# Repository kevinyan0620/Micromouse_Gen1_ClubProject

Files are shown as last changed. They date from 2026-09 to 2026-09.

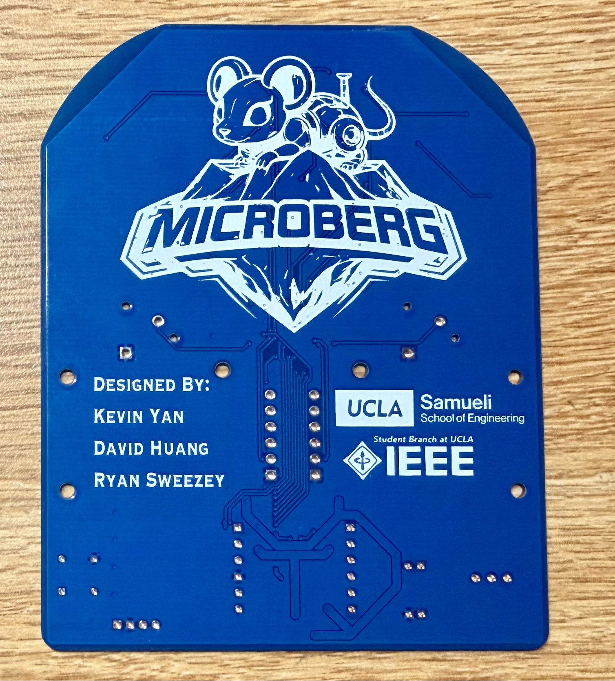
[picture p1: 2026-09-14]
Pictures/Design_Pictures.jpeg

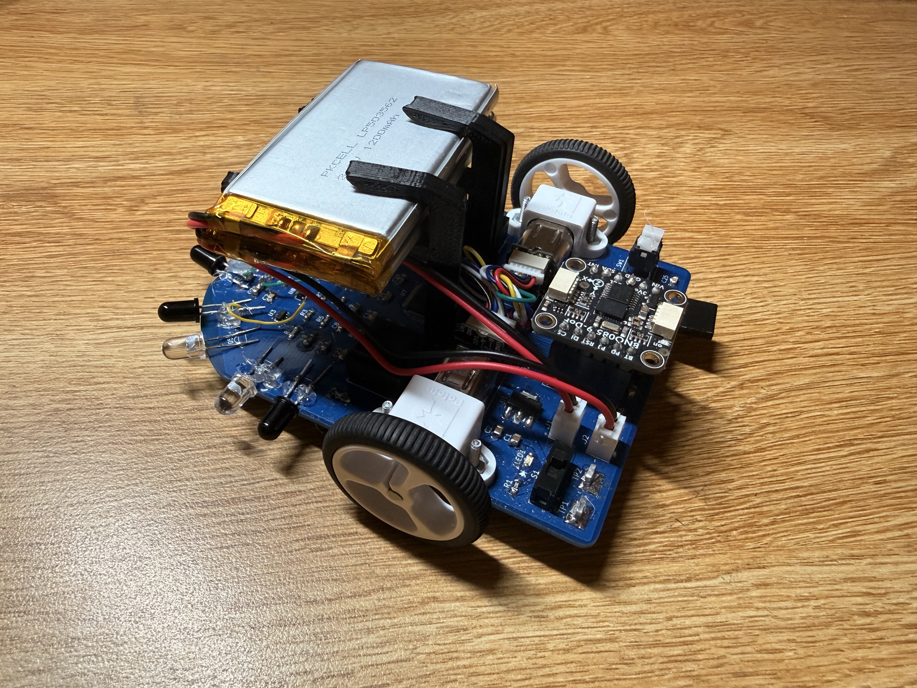
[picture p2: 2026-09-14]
Pictures/Micromouse_Pictures.jpeg

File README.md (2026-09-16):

# Autonomous Micromouse (Generation 1)

This repository details the hardware and firmware design of a Generation 1 autonomous Micromouse. Built from scratch, the project encompasses component selection, schematic capture, 2-layer PCB layout, and embedded C programming. 

Here is some pictures of our PCB design and our Micromouse!

| Our Group Logo | Final Micromouse |
| --- | --- |
|Design_Pictures |Micromouse_Pictures |

* **Competition Result:** Placed **5th Nationally** and **2nd Schoolwide** at the All American Micromouse Competition (AAMC).
* **See It In Action:** [Watch our competition run on AAMC Live (starts at 51:30)](https://youtu.be/dCLFL7v4gUA?t=3090)

We are actively iterating on this design to compete again in the upcoming AAMC!

## Repository Structure

* `/Micromouse_STM32ApplicationCode`: Contains the embedded C firmware and project files configured for the STM32 environment.

* `/The Mouse`: The master KiCad project directory. Includes the full system schematics (wiring) and the 2-layer PCB layout files.

* `/Micromouse_Parts`: Custom KiCad footprint and symbol libraries created for this project. These can be directly imported into KiCad for viewing or reuse.

* `/Pictures`: Photographic documentation of the hardware assembly, revisions, and competition runs.

* `Final Pinout.png`: A comprehensive STM32 pin mapping reference diagram required to understand the hardware-firmware interface.

* `Micromouse_BillOfMaterials_AssemblyVersion.xlsx`: A detailed assembly BOM mapped by reference designator (e.g., R10) and subsystem, used for manufacturing guidance and population.

* `Micromouse_BillOfMaterials_SubmitVersion.xlsx`: A consolidated purchasing BOM with grouped components and quantities, optimized for vendor procurement (e.g., Digi-Key).

* `Test_Run_With_Small_Maze.MOV`: Video demonstration of the maze-solving algorithm in a scaled-down test environment prior to the competition.

## Hardware Architecture

The electrical hardware was designed to balance form factor with sensor coverage and ease of routing. Components were carefully sourced via Digi-Key, maintaining a strict Bill of Materials (BOM) throughout the project lifecycle.

*   **Microcontroller:** STM32 MCU (STM32F205RET7) serving as the core processor, with pinouts optimized during the layout phase to minimize trace crossings and accommodate physical wiring constraints.
*   **PCB Design:** A fully hand-soldered, custom 2-layer board. Components were sourced via Digi-Key with a comprehensive Bill of Materials (BOM) managed throughout the project lifecycle.
*   **Sensor Array:** Custom 45-degree angled IR sensor placement for superior wall-detection accuracy compared to standard orthogonal layouts.
*   **Inertial Measurement:** Adafruit BNO085 9-DOF IMU (Gyroscope/Accelerometer) integrated to ensure highly accurate, drift-compensated turns.
*   **User Interface:** 4 onboard user LEDs and 2 tactile buttons for rapid field-diagnostics and mode switching.

## Firmware and Control Systems

The software stack is written entirely in bare-metal C, focusing on real-time control and algorithmic efficiency.

*   **Navigation:** Implemented a flood-fill algorithm for autonomous maze solving and optimal path calculation.
*   **Motor Control:** Closed-loop PID control utilizing encoder feedback to maintain precise velocities.
*   **Traction Management:** Engineered acceleration and deceleration profiles to prevent wheel slip, ensuring accurate encoder tick counts.
*   **Physical Realignment:** The mouse was designed to purposefully "tap" the wall during the run once every 10 actions (forward or turning), when appropriate. This is done by moving forward to tap the front wall, then slightly back up to the center of the maze. This helps realign the micromouse in the maze and avoid tiny errors from accumulating and ruining the run.
*   **Operational Modes:** Designed a dual-mode system allowing a seamless transition from "Search Mode" (active IR and flood-fill) to "Speed Run Mode" (sensorless execution of the stored optimal path).

## Assembly, Debugging, and Rework

Building the physical hardware required extensive hands-on debugging, microscope soldering, and creative problem-solving.

| Challenge | Root Cause | Engineering Solution |
| :--- | :--- | :--- |
| **Broken PCB Pad** | Mechanical stress / heat | Reworked using a microscope and microscopic gauge wire to bridge the broken connection. |
| **MCU Assembly** | Fine-pitch footprint | Successfully hand-soldered the tiny MCU using heavy flux, a microscope, and drag-soldering techniques within two attempts. |
| **IR Sensor Verification** | Invisible IR spectrum | Utilized a smartphone camera to detect the IR emitter's dim purple glow, and a phone flashlight (which emits IR) to stimulate and test the IR receivers. |

## Lessons Learned & Generation 2 Roadmap

This first iteration provided invaluable lessons in Design for Manufacturability (DFM) and edge-case software handling. The following improvements are slated for the Generation 2 Micromouse:

*   **Component Selection:** Transitioning from Surface Mount (SMD) IR sensors to Through-Hole (THT) alternatives. SMD optoelectronics proved highly susceptible to thermal damage during hand-soldering.
*   **Connector Standardization:** Replacing the non-standard ST-Link header with a standard 0.1-inch pitch 1x4 connector to streamline firmware flashing.
*   **Firmware Edge Cases:** Patching a known bug that occasionally causes indefinite looping turns under extreme, undocumented maze conditions.
*   **Path Optimization:** Upgrading the Speed Run mode algorithm to calculate and execute diagonal movements, significantly reducing cornering time.

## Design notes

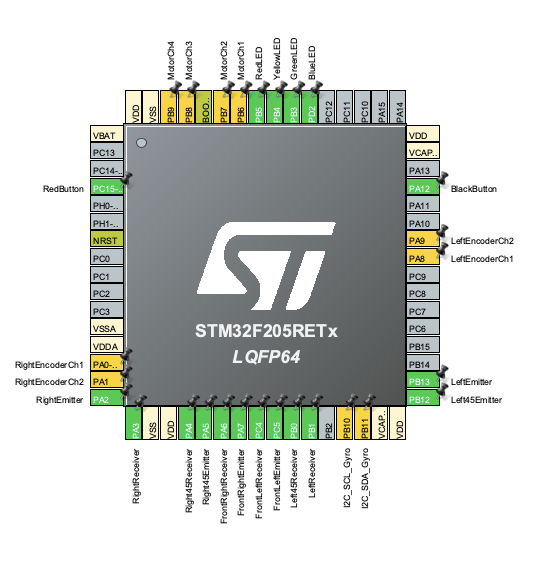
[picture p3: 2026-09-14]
Final Pinout.png

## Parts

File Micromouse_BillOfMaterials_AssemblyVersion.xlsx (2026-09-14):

Category | Item | Product Number | Designators | Detail | Quantity | Unit Price | Purchase Link | Datasheet | Notes |  | Total Price | 172.47
Power Delivery | Voltage Regulator | AZ1117IH-3.3TRG1 | U1 | Linear Voltage Regulator IC Positive Fixed 1 Output 1A SOT-223-3 | 1 | 0.24 | https://www.digikey.com/en/products/detail/diodes-incorporated/AZ1117IH-3-3TRG1/5699682 | https://www.diodes.com/assets/Datasheets/AZ1117I.pdf
Power Delivery | Capacitor | GRM21BR61C106KE15L | C1 | 10 µF ±10% 16V Ceramic Capacitor X5R 0805 (2012 Metric) | 1 | 0.13 | https://www.digikey.com/en/products/detail/murata-electronics/GRM21BR61C106KE15L/965900 | https://search.murata.co.jp/Ceramy/image/img/A01X/G101/ENG/GRM21BR61C106KE15-01.pdf | Input Decoupling |  | Submit Version (https://docs.google.com/spreadsheets/d/1v3HhBURM-rz71dSanRjxjPIMUvfi7GNW-tEQRfmBjM0/edit?usp=sharing)
Power Delivery | Capacitor | CL21A226KOQNNNE | C2 | 22 µF ±10% 16V Ceramic Capacitor X5R 0805 (2012 Metric) | 1 | 0.33 | https://www.digikey.com/en/products/detail/samsung-electro-mechanics/CL21A226KOQNNNE/5961010 | https://mm.digikey.com/Volume0/opasdata/d220001/medias/docus/6462/CL21A226KOQNNNE-datasheet.pdf | Output Decoupling |  | https://www.digikey.com/en/products/detail/same-sky-formerly-cui-devices/SSK02-FPH-254-A4/28772197
Power Delivery | JST Connector | B2B-PH-K-S | J1, J2 | Connector Header Through Hole 2 position 0.079" (2.00mm) | 2 | 0.1 | https://www.digikey.com/en/products/detail/jst-sales-america-inc/B2B-PH-K-S-LF-SN/455-1704-ND/926611 | https://www.jst-mfg.com/product/pdf/eng/ePH.pdf | Battery JST Connector |  | https://www.digikey.com/en/products/detail/ams-osram-usa-inc/SFH-313-FA-3-4/1630112
Power Delivery | Switch | EG1218 | S1 | Slide Switch SPDT Through Hole | 1 | 0.84 | https://www.digikey.com/en/products/detail/e-switch/EG1218/101726 | https://configured-product-images.s3.amazonaws.com/Datasheets/EG.pdf | Switch On/Off |  | https://www.digikey.com/en/products/detail/inolux/INL-5AMIR15/10384755
Power Delivery | Green LED | LTST-C170GKT | LED1 | Green 569nm LED Indication - Discrete 2.1V 0805 (2012 Metric) | 1 | 0.1 | https://www.digikey.com/en/products/detail/liteon/LTST-C170GKT/269226 | https://mm.digikey.com/Volume0/opasdata/d220001/medias/docus/895/LTST-C170GKT.pdf | Power On/Off Indicator
Power Delivery | Resistor | ERA-6AEB221V | R1 | 220 Ohms ±0.1% 0.125W, 1/8W Chip Resistor 0805 (2012 Metric) Automotive AEC-Q200 Thin Film | 1 | 0.1 | https://www.digikey.com/en/products/detail/panasonic-electronic-components/ERA-6AEB221V/1465732 | https://industrial.panasonic.com/cdbs/www-data/pdf/RDM0000/AOA0000C307.pdf | Power LED Resistor
Power Delivery | Test Point Pins | 5095 | TP1, TP2 | PC Test Point, Compact Phosphor Bronze Tin Plating Surface Mount Mounting Type | 2 | 0.4 | https://www.digikey.com/en/products/detail/keystone-electronics/5095/12751699 | http://www.keystoneelectronics.biz/ENG._DEPT/WEB_ORACLE/PDF/PDF%20CAT%20NO%20DRAWINGS/5000-5999/5095.PDF | Test Point for VBat and GND
Motor Control | H Bridge IC | L293DD | U2 | Bipolar Motor Driver Parallel 20-SO | 1 | 8.56 | https://www.digikey.com/en/products/detail/stmicroelectronics/L293DD/585913 | https://www.st.com/content/ccc/resource/technical/document/datasheet/04/ac/22/f9/20/5d/43/a1/CD00000059.pdf/files/CD00000059.pdf/jcr:content/translations/en.C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 | Motor Control H Bridge
Motor Control | Capacitor | GRM21BR61C106KE15L | C3 | 10 µF ±10% 16V Ceramic Capacitor X5R 0805 (2012 Metric) | 1 | 0.13 | https://www.digikey.com/en/products/detail/murata-electronics/GRM21BR61C106KE15L/965900 | https://search.murata.co.jp/Ceramy/image/img/A01X/G101/ENG/GRM21BR61C106KE15-01.pdf | Vs Decoupling 1 | Same as 3
Motor Control | Capacitor | VJ0805Y104JXAAT | C5 | 0.1 µF ±5% 50V Ceramic Capacitor X7R 0805 (2012 Metric) | 1 | 0.39 | https://www.digikey.com/en/products/detail/vishay-vitramon/VJ0805Y104JXAAT/2776727 | https://www.vishay.com/docs/45199/vjcommercialseries.pdf | Vss Decoupling 1
Motor Control | Capacitor | GRT21BR61H475KE13L | C4, C6 | 4.7 µF ±10% 50V Ceramic Capacitor X5R 0805 (2012 Metric) | 2 | 0.17 | https://www.digikey.com/en/products/detail/murata-electronics/GRT21BR61H475KE13L/5416816 | https://search.murata.co.jp/Ceramy/image/img/A01X/G101/ENG/GRT21BR61H475KE13-01.pdf | Vs Decoupling 2; Vss Decoupling 2
IR Emitter | Capacitor | VJ0805Y104JXAAT | C8, C10, C12, C14, C29, C31 | 0.1 µF ±5% 50V Ceramic Capacitor X7R 0805 (2012 Metric) | 6 | 0.39 | https://www.digikey.com/en/products/detail/vishay-vitramon/VJ0805Y104JXAAT/2776727 | https://www.vishay.com/docs/45199/vjcommercialseries.pdf | IR Emitter Bypass 1 | Same as 13
IR Emitter | Capacitor | GRT21BR61H475KE13L | C7, C9, C11, C13, C28, C30 | 4.7 µF ±10% 50V Ceramic Capacitor X5R 0805 (2012 Metric) | 6 | 0.17 | https://www.digikey.com/en/products/detail/murata-electronics/GRT21BR61H475KE13L/5416816 | https://search.murata.co.jp/Ceramy/image/img/A01X/G101/ENG/GRT21BR61H475KE13-01.pdf | IR Emitter Bypass 2 | Same as 14
IR Emitter | IR Emitter | INL-5AMIR15 | D1, D2, D3, D4, D5, D6 | Infrared (IR) Emitter 880nm 1.3V 100mA 7.8mW/sr @ 20mA 15° Radial | 6 | 0.92 | https://www.digikey.com/en/products/detail/inolux/INL-5AMIR15/10384755 | https://www.inolux-corp.com/datasheet/IR/Emitter/5mm%20Lamp/INL-5AMIR15_V1.0.pdf
IR Emitter | MOSFET | MMBF170LT1G | U3, U4, U5, U6, U8, U9 | N-Channel 60 V 500mA (Ta) 225mW (Ta) Surface Mount SOT-23-3 (TO-236) | 6 | 0.26 | https://www.digikey.com/en/products/detail/onsemi/MMBF170LT1G/919578 | https://www.onsemi.com/pdf/datasheet/mmbf170lt1-d.pdf
IR Emitter | Resistor | ERA-6AEB101V | R2, R6, R10, R14, R26, R30 | 100 Ohms ±0.1% 0.125W, 1/8W Chip Resistor 0805 (2012 Metric) Automotive AEC-Q200 Thin Film | 6 | 0.1 | https://www.digikey.com/en/products/detail/panasonic-electronic-components/ERA-6AEB101V/1465724 | https://industrial.panasonic.com/cdbs/www-data/pdf/RDM0000/AOA0000C307.pdf | MCU Pin Current Limiter Resistor
IR Emitter | Resistor | ERA-6AEB510V | R4, R8, R12, R16, R28, R32 | 51 Ohms ±0.1% 0.125W, 1/8W Chip Resistor 0805 (2012 Metric) Automotive AEC-Q200 Thin Film | 6 | 0.1 | https://www.digikey.com/en/products/detail/panasonic-electronic-components/ERA-6AEB510V/1465717 | https://industrial.panasonic.com/cdbs/www-data/pdf/RDM0000/AOA0000C307.pdf | IR Emitter Resistor
IR Emitter | Resistor | ERA-6AEB473V | R3, R7, R11, R15, R27, R31 | 47 kOhms ±0.1% 0.125W, 1/8W Chip Resistor 0805 (2012 Metric) Automotive AEC-Q200 Thin Film | 6 | 0.1 | https://www.digikey.com/en/products/detail/panasonic-electronic-components/ERA-6AEB473V/1465789 | https://industrial.panasonic.com/cdbs/www-data/pdf/RDM0000/AOA0000C307.pdf | Pull Down Resistor
IR Receiver | IR Receiver | SFH 313 FA-3/4 | Q1, Q2, Q3, Q4, Q5, Q6 | Phototransistors 870nm Top View Radial | 6 | 0.83 | https://www.digikey.com/en/products/detail/ams-osram-usa-inc/SFH-313-FA-3-4/1630112 | https://look.ams-osram.com/m/5f84917e436bcd12/original/SFH-313-FA.pdf
IR Receiver | Resistor | ERA-6AEB182V | R5, R9, R13, R17, R29, R33 | 1.8 kOhms ±0.1% 0.125W, 1/8W Chip Resistor 0805 (2012 Metric) Automotive AEC-Q200 Thin Film | 6 | 0.1 | https://www.digikey.com/en/products/detail/panasonic-electronic-components/ERA-6AEB182V/1465755 | https://industrial.panasonic.com/cdbs/www-data/pdf/RDM0000/AOA0000C307.pdf | IR Reciever Limiting Resistor
Microcontroller | STM 32 | STM32F205RET7 | U7 | High-performance Arm Cortex-M3 MCU with 512 Kbytes of Flash memory, 120 MHz CPU, ART Accelerator | 1 | 11.52 | https://estore.st.com/en/stm32f205ret7-cpn.html | https://www.st.com/resource/en/datasheet/stm32f205rb.pdf
Microcontroller | Capacitor | VJ0805Y104JXAAT | C17, C18, C19, C21, C22, C24, C25 | 0.1 µF ±5% 50V Ceramic Capacitor X7R 0805 (2012 Metric) | 6 | 0.39 | https://www.digikey.com/en/products/detail/vishay-vitramon/VJ0805Y104JXAAT/2776727 | https://www.vishay.com/docs/45199/vjcommercialseries.pdf | Microcontroller Decoupling Capacitor | Same as 13
Microcontroller | Capacitor | GRM21BC72A105KE01L | C23 | 1 µF ±10% 100V Ceramic Capacitor X7S 0805 (2012 Metric) | 1 | 0.36 | https://www.digikey.com/en/products/detail/murata-electronics/GRM21BC72A105KE01L/6606093 | https://search.murata.co.jp/Ceramy/image/img/A01X/G101/ENG/GRM21BC72A105KE01-01.pdf | Microcontroller Decoupling Capacitor
Microcontroller | Capacitor | GRM21BD72A225KE01L | C15, C16 | 2.2 µF ±10% 100V Ceramic Capacitor X7T 0805 (2012 Metric) | 2 | 0.4 | https://www.digikey.com/en/products/detail/murata-electronics/GRM21BD72A225KE01L/16033492 | https://search.murata.co.jp/Ceramy/image/img/A01X/G101/ENG/GRM21BD72A225KE01-01A.pdf | Microcontroller Decoupling Capacitor
Microcontroller | Capacitor | GRM21BR61C106KE15L | C20 | 10 µF ±10% 16V Ceramic Capacitor X5R 0805 (2012 Metric) | 1 | 0.13 | https://www.digikey.com/en/products/detail/murata-electronics/GRM21BR61C106KE15L/965900 | https://search.murata.co.jp/Ceramy/image/img/A01X/G101/ENG/GRM21BR61C106KE15-01.pdf | Microcontroller Decoupling Capacitor | Same as 3
Microcontroller | Resistor | ERA-6AEB103V | R18, R19 | 10 kOhms ±0.1% 0.125W, 1/8W Chip Resistor 0805 (2012 Metric) Automotive AEC-Q200 Thin Film | 2 | 0.1 | https://www.digikey.com/en/products/detail/panasonic-electronic-components/ERA-6AEB103V/1465773 | https://industrial.panasonic.com/cdbs/www-data/pdf/RDM0000/AOA0000C307.pdf | Microcontroller Resistor
Microcontroller | Pushbutton | TR1-01 | SW1 | Pushbutton Switch SPST-NO Standard Through Hole | 1 | 0.86 | https://www.digikey.com/en/products/detail/nidec-components-corporation/TR1-01/5125294 | https://www.nidec-components.com/e/catalog/switch/tm&tr.pdf | Microcontroller Reset Button
Microcontroller | Female Socket | SSK02-FPH-254-A4 | J5 | 4 Position Header Connector 0.100" (2.54mm) Through Hole Gold | 1 | 0.32 | https://www.digikey.com/en/products/detail/same-sky-formerly-cui-devices/SSK02-FPH-254-A4/28772197 | https://www.sameskydevices.com/product/resource/ssk02-fph-254.pdf | Socket for ST Link
User LED | Resistor | ERA-6AEB221V | R20, R21, R22, R23 | 220 Ohms ±0.1% 0.125W, 1/8W Chip Resistor 0805 (2012 Metric) Automotive AEC-Q200 Thin Film | 4 | 0.1 | https://www.digikey.com/en/products/detail/panasonic-electronic-components/ERA-6AEB221V/1465732 | https://industrial.panasonic.com/cdbs/www-data/pdf/RDM0000/AOA0000C307.pdf | User LED Resistor
User LED | Red LED | LTST-C171KRKT | LED2 | Red 631nm LED Indication - Discrete 2V 0805 (2012 Metric) | 1 | 0.13 | https://www.digikey.com/en/products/detail/liteon/LTST-C171KRKT/386801 | https://optoelectronics.liteon.com/upload/download/DS22-2000-109/LTST-C171KRKT.pdf | User Red LED
User LED | Yellow LED | LTST-C170KSKT | LED3 | Yellow 591nm LED Indication - Discrete 2.1V 0805 (2012 Metric) | 1 | 0.14 | https://www.digikey.com/en/products/detail/liteon/LTST-C170KSKT/386781 | https://optoelectronics.liteon.com/upload/download/DS-22-99-0188/LTST-C170KSKT.pdf | User Yellow LED
User LED | Green LED | LTST-C170GKT | LED4 | Green 569nm LED Indication - Discrete 2.1V 0805 (2012 Metric) | 1 | 0.1 | https://www.digikey.com/en/products/detail/liteon/LTST-C170GKT/269226 | https://mm.digikey.com/Volume0/opasdata/d220001/medias/docus/895/LTST-C170GKT.pdf | User Green LED
User LED | Blue LED | LTST-C170TBKT | LED5 | Blue 470nm LED Indication - Discrete 3.3V 0805 (2012 Metric) | 1 | 0.22 | https://www.digikey.com/en/products/detail/liteon/LTST-C170TBKT/388527 | https://optoelectronics.liteon.com/upload/download/DS-22-99-0226/LTST-C170TBKT.pdf | User Blue LED
User Button | Capacitor | VJ0805Y104JXAAT | C26, C27 | 0.1 µF ±5% 50V Ceramic Capacitor X7R 0805 (2012 Metric) | 2 | 0.39 | https://www.digikey.com/en/products/detail/vishay-vitramon/VJ0805Y104JXAAT/2776727 | https://www.vishay.com/docs/45199/vjcommercialseries.pdf | User Button Debouncing | Same as 13
User Button | Resistor | ERA-6AEB472V | R24, R25 | 4.7 kOhms ±0.1% 0.125W, 1/8W Chip Resistor 0805 (2012 Metric) Automotive AEC-Q200 Thin Film | 2 | 0.1 | https://www.digikey.com/en/products/detail/panasonic-electronic-components/ERA-6AEB472V/1465765 | https://industrial.panasonic.com/cdbs/www-data/pdf/RDM0000/AOA0000C307.pdf | User Button Pull-up Resistor
User Button | Push Button | KS11R22CQD | SW2 | Pushbutton Switch SPST-NO Keyswitch Through Hole | 1 | 2.84 | https://www.digikey.com/en/products/detail/c-k/KS11R22CQD/332670 | https://www.ckswitches.com/media/1342/ks.pdf | Black User Button
User Button | Push Button | KS11R23CQD | SW3 | Pushbutton Switch SPST-NO Keyswitch Through Hole | 1 | 2.84 | https://www.digikey.com/en/products/detail/c-k/KS11R23CQD/332672 | https://www.ckswitches.com/media/1342/ks.pdf | Red User Button
Gyroscope | Gyroscope | 4754 | On top of J6, J7 | Adafruit 9-DOF Orientation IMU Fusion Breakout - BNO085 (BNO080) - STEMMA QT / Qwiic | 1 | 24.95 | https://www.adafruit.com/product/4754#technical-details | https://cdn-learn.adafruit.com/downloads/pdf/adafruit-9-dof-orientation-imu-fusion-breakout-bno085.pdf
Gyroscope | Socket | D01-9970642 | J6, J7 | 6 (1 x 6) Pos SIP Socket Gold Through Hole | 2 | 0.63 | https://www.digikey.com/en/products/detail/harwin-inc/D01-9970642/3727951 | https://content.harwin.com/m/e0b6c35948424a73/original/DRG-00097-Technical-Drawing-Datasheet-D01-997-pdf.pdf | Socket for Gyroscope
Hardware | Motor | 2378 | NA | 30:1 Micro Metal Gearmotor MP 6V with Extended Motor Shaft | 2 | 24.95 | https://www.pololu.com/product/2378
Hardware | Encoder Pair | 4760 | NA | Magnetic Encoder Pair Kit with Top-Entry Connector for Micro Metal Gearmotors, 12 CPR, 2.7-18V | 1 | 8.95 | https://www.pololu.com/product/4760
Hardware | Motor Mount | 1086 | NA | Pololu Micro Metal Gearmotor Bracket Pair - White | 1 | 2.95 | https://www.pololu.com/product/1086
Hardware | Wheels | 1088 | NA | Pololu Wheel 32×7mm Pair - White | 1 | 4.45 | https://www.pololu.com/product/1088
Hardware | LiPo Battery | 258 | NA | Lithium Ion Polymer Battery - 3.7v 1200mAh | 2 | 9.95 | https://www.adafruit.com/product/258
Hardware | LiPo Battery Charger | 1304 | NA | Adafruit Micro Lipo - USB LiIon/LiPoly charger - v2 | 1 | 5.95 | https://www.adafruit.com/product/1304

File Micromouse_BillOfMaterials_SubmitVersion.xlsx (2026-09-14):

Item | Product Number | Detail | Quantity | Unit Price | Purchase Link | Datasheet | Notes | Total Price | 211.09
Voltage Regulator | AZ1117IH-3.3TRG1 | Linear Voltage Regulator IC Positive Fixed 1 Output 1A SOT-223-3 | 1 | 0.24 | https://www.digikey.com/en/products/detail/diodes-incorporated/AZ1117IH-3-3TRG1/5699682 | https://www.diodes.com/assets/Datasheets/AZ1117I.pdf
Capacitor | GRM21BR61C106KE15L | 10 µF ±10% 16V Ceramic Capacitor X5R 0805 (2012 Metric) | 6 | 0.13 | https://www.digikey.com/en/products/detail/kyocera-avx/0805YD106KAT2A/1913255 | https://search.murata.co.jp/Ceramy/image/img/A01X/G101/ENG/GRM21BR61C106KE15-01.pdf | Input Decoupling | Old Order: https://www.digikey.com/en/products/detail/murata-electronics/GRM21BR61C106KE15L/965900
Capacitor | CL21A226KOQNNNE | 22 µF ±10% 16V Ceramic Capacitor X5R 0805 (2012 Metric) | 3 | 0.33 | https://www.digikey.com/en/products/detail/samsung-electro-mechanics/CL21A226KOQNNNG/8021509 | https://mm.digikey.com/Volume0/opasdata/d220001/medias/docus/6462/CL21A226KOQNNNE-datasheet.pdf | Output Decoupling | Old Order: https://www.digikey.com/en/products/detail/samsung-electro-mechanics/CL21A226KOQNNNE/5961010
JST Connector | B2B-PH-K-S | Connector Header Through Hole 2 position 0.079" (2.00mm) | 2 | 0.1 | https://www.digikey.com/en/products/detail/jst-sales-america-inc/B2B-PH-K-S-LF-SN/455-1704-ND/926611 | https://www.jst-mfg.com/product/pdf/eng/ePH.pdf | Battery JST Connector
Switch | EG1218 | Slide Switch SPDT Through Hole | 1 | 0.84 | https://www.digikey.com/en/products/detail/e-switch/EG1218/101726 | https://configured-product-images.s3.amazonaws.com/Datasheets/EG.pdf | Switch On/Off
Green LED | LTST-C170GKT | Green 569nm LED Indication - Discrete 2.1V 0805 (2012 Metric) | 3 | 0.1 | https://www.digikey.com/en/products/detail/liteon/LTST-C170GKT/269226 | https://mm.digikey.com/Volume0/opasdata/d220001/medias/docus/895/LTST-C170GKT.pdf | Power On/Off Indicator
Resistor | ERA-6AEB221V | 220 Ohms ±0.1% 0.125W, 1/8W Chip Resistor 0805 (2012 Metric) Automotive AEC-Q200 Thin Film | 3 | 0.1 | https://www.digikey.com/en/products/detail/panasonic-electronic-components/ERA-6AEB221V/1465732 | https://industrial.panasonic.com/cdbs/www-data/pdf/RDM0000/AOA0000C307.pdf | Power LED Resistor
Test Point Pins | 5095 | PC Test Point, Compact Phosphor Bronze Tin Plating Surface Mount Mounting Type | 4 | 0.4 | https://www.digikey.com/en/products/detail/keystone-electronics/5095/12751699 | http://www.keystoneelectronics.biz/ENG._DEPT/WEB_ORACLE/PDF/PDF%20CAT%20NO%20DRAWINGS/5000-5999/5095.PDF | Test Point for VBat and GND
H Bridge IC | L293DD | Bipolar Motor Driver Parallel 20-SO | 2 | 8.56 | https://www.digikey.com/en/products/detail/stmicroelectronics/L293DD/585913 | https://www.st.com/content/ccc/resource/technical/document/datasheet/04/ac/22/f9/20/5d/43/a1/CD00000059.pdf/files/CD00000059.pdf/jcr:content/translations/en.C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 | Motor Control H Bridge
Capacitor | VJ0805Y104JXAAT | 0.1 µF ±5% 50V Ceramic Capacitor X7R 0805 (2012 Metric) | 18 | 0.39 | https://www.digikey.com/en/products/detail/kemet/C0805C104J5RACTU/411446 | https://www.vishay.com/docs/45199/vjcommercialseries.pdf | Vss Decoupling 1 | Old Order: https://www.digikey.com/en/products/detail/vishay-vitramon/VJ0805Y104JXAAT/2776727
Capacitor | GRT21BR61H475KE13L | 4.7 µF ±10% 50V Ceramic Capacitor X5R 0805 (2012 Metric) | 9 | 0.17 | https://www.digikey.com/en/products/detail/murata-electronics/GRT21BR61H475KE13L/5416816 | https://search.murata.co.jp/Ceramy/image/img/A01X/G101/ENG/GRT21BR61H475KE13-01.pdf | Vs Decoupling 2; Vss Decoupling 2
IR Emitter | INL-5AMIR15 | Infrared (IR) Emitter 880nm 1.3V 100mA 7.8mW/sr @ 20mA 15° Radial | 7 | 0.92 | https://www.digikey.com/en/products/detail/inolux/INL-5AMIR15/10384755 | https://www.inolux-corp.com/datasheet/IR/Emitter/5mm%20Lamp/INL-5AMIR15_V1.0.pdf
MOSFET | MMBF170LT1G | N-Channel 60 V 500mA (Ta) 225mW (Ta) Surface Mount SOT-23-3 (TO-236) | 8 | 0.26 | https://www.digikey.com/en/products/detail/onsemi/FDN5630/965610 | https://www.onsemi.com/pdf/datasheet/mmbf170lt1-d.pdf |  | Old Order: https://www.digikey.com/en/products/detail/onsemi/MMBF170LT1G/919578
Resistor | ERA-6AEB101V | 100 Ohms ±0.1% 0.125W, 1/8W Chip Resistor 0805 (2012 Metric) Automotive AEC-Q200 Thin Film | 8 | 0.1 | https://www.digikey.com/en/products/detail/susumu/RG2012P-101-B-T5/1241036 | https://industrial.panasonic.com/cdbs/www-data/pdf/RDM0000/AOA0000C307.pdf | MCU Pin Current Limiter Resistor | Old Order: https://www.digikey.com/en/products/detail/panasonic-electronic-components/ERA-6AEB101V/1465724
Resistor | ERA-6AEB510V | 51 Ohms ±0.1% 0.125W, 1/8W Chip Resistor 0805 (2012 Metric) Automotive AEC-Q200 Thin Film | 8 | 0.1 | https://www.digikey.com/en/products/detail/panasonic-electronic-components/ERA-6AEB510V/1465717 | https://industrial.panasonic.com/cdbs/www-data/pdf/RDM0000/AOA0000C307.pdf | IR Emitter Resistor
Resistor | ERA-6AEB473V | 47 kOhms ±0.1% 0.125W, 1/8W Chip Resistor 0805 (2012 Metric) Automotive AEC-Q200 Thin Film | 8 | 0.1 | https://www.digikey.com/en/products/detail/panasonic-electronic-components/ERA-6AEB473V/1465789 | https://industrial.panasonic.com/cdbs/www-data/pdf/RDM0000/AOA0000C307.pdf | Pull Down Resistor
IR Receiver | SFH 313 FA-3/4 | Phototransistors 870nm Top View Radial | 7 | 0.83 | https://www.digikey.com/en/products/detail/ams-osram-usa-inc/SFH-313-FA-3-4/1630112 | https://look.ams-osram.com/m/5f84917e436bcd12/original/SFH-313-FA.pdf
Resistor | ERA-6AEB182V | 1.8 kOhms ±0.1% 0.125W, 1/8W Chip Resistor 0805 (2012 Metric) Automotive AEC-Q200 Thin Film | 8 | 0.1 | https://www.digikey.com/en/products/detail/panasonic-electronic-components/ERA-6AEB182V/1465755 | https://industrial.panasonic.com/cdbs/www-data/pdf/RDM0000/AOA0000C307.pdf | IR Reciever Limiting Resistor
STM 32 | STM32F205RET7 | High-performance Arm Cortex-M3 MCU with 512 Kbytes of Flash memory, 120 MHz CPU, ART Accelerator | 2 | 11.52 | https://estore.st.com/en/stm32f205ret7-cpn.html | https://www.st.com/resource/en/datasheet/stm32f205rb.pdf
Capacitor | GRM21BC72A105KE01L | 1 µF ±10% 100V Ceramic Capacitor X7S 0805 (2012 Metric) | 3 | 0.36 | https://www.digikey.com/en/products/detail/murata-electronics/GRM21BC72A105KE01L/6606093 | https://search.murata.co.jp/Ceramy/image/img/A01X/G101/ENG/GRM21BC72A105KE01-01.pdf | Microcontroller Decoupling Capacitor
Capacitor | GRM21BD72A225KE01L | 2.2 µF ±10% 100V Ceramic Capacitor X7T 0805 (2012 Metric) | 4 | 0.4 | https://www.digikey.com/en/products/detail/murata-electronics/GRM21BD72A225KE01L/16033492 | https://search.murata.co.jp/Ceramy/image/img/A01X/G101/ENG/GRM21BD72A225KE01-01A.pdf | Microcontroller Decoupling Capacitor
Resistor | ERA-6AEB103V | 10 kOhms ±0.1% 0.125W, 1/8W Chip Resistor 0805 (2012 Metric) Automotive AEC-Q200 Thin Film | 5 | 0.1 | https://www.digikey.com/en/products/detail/panasonic-electronic-components/ERA-6AEB103V/1465773 | https://industrial.panasonic.com/cdbs/www-data/pdf/RDM0000/AOA0000C307.pdf | Microcontroller Resistor
Pushbutton | TR1-01 | Pushbutton Switch SPST-NO Standard Through Hole | 1 | 0.86 | https://www.digikey.com/en/products/detail/nidec-components-corporation/TR1-01/5125294 | https://www.nidec-components.com/e/catalog/switch/tm&tr.pdf | Microcontroller Reset Button
Female Socket | SSK02-FPH-254-A4 | 4 Position Header Connector 0.100" (2.54mm) Through Hole Gold | 1 | 0.32 | https://www.digikey.com/en/products/detail/same-sky-formerly-cui-devices/SSK02-FPH-254-A4/28772197 | https://www.sameskydevices.com/product/resource/ssk02-fph-254.pdf | Socket for ST Link (https://www.sameskydevices.com/product/resource/ssk02-fph-254.pdf)
Resistor | ERA-6AEB221V | 220 Ohms ±0.1% 0.125W, 1/8W Chip Resistor 0805 (2012 Metric) Automotive AEC-Q200 Thin Film | 6 | 0.1 | https://www.digikey.com/en/products/detail/panasonic-electronic-components/ERA-6AEB221V/1465732 | https://industrial.panasonic.com/cdbs/www-data/pdf/RDM0000/AOA0000C307.pdf | User LED Resistor
Red LED | LTST-C171KRKT | Red 631nm LED Indication - Discrete 2V 0805 (2012 Metric) | 2 | 0.13 | https://www.digikey.com/en/products/detail/liteon/LTST-C171KRKT/386801 | https://optoelectronics.liteon.com/upload/download/DS22-2000-109/LTST-C171KRKT.pdf | User Red LED
Yellow LED | LTST-C170KSKT | Yellow 591nm LED Indication - Discrete 2.1V 0805 (2012 Metric) | 2 | 0.14 | https://www.digikey.com/en/products/detail/liteon/LTST-C170YKT/269247 | https://optoelectronics.liteon.com/upload/download/DS-22-99-0188/LTST-C170KSKT.pdf | User Yellow LED | Old Order: https://www.digikey.com/en/products/detail/liteon/LTST-C170KSKT/386781
Blue LED | LTST-C170TBKT | Blue 470nm LED Indication - Discrete 3.3V 0805 (2012 Metric) | 2 | 0.22 | https://www.digikey.com/en/products/detail/liteon/LTST-C170TBKT/388527 | https://optoelectronics.liteon.com/upload/download/DS-22-99-0226/LTST-C170TBKT.pdf | User Blue LED
Resistor | ERA-6AEB472V | 4.7 kOhms ±0.1% 0.125W, 1/8W Chip Resistor 0805 (2012 Metric) Automotive AEC-Q200 Thin Film | 6 | 0.1 | https://www.digikey.com/en/products/detail/panasonic-electronic-components/ERA-6AEB472V/1465765 | https://industrial.panasonic.com/cdbs/www-data/pdf/RDM0000/AOA0000C307.pdf | User Button Pull-up Resistor
Push Button | KS11R22CQD | Pushbutton Switch SPST-NO Keyswitch Through Hole | 1 | 2.84 | https://www.digikey.com/en/products/detail/c-k/KS11R22CQD/332670 | https://www.ckswitches.com/media/1342/ks.pdf | Black User Button
Push Button | KS11R23CQD | Pushbutton Switch SPST-NO Keyswitch Through Hole | 1 | 2.84 | https://www.digikey.com/en/products/detail/c-k/KS11R23CQD/332672 | https://www.ckswitches.com/media/1342/ks.pdf | Red User Button
Gyroscope | 4754 | Adafruit 9-DOF Orientation IMU Fusion Breakout - BNO085 (BNO080) - STEMMA QT / Qwiic | 1 | 24.95 | https://www.adafruit.com/product/4754#technical-details | https://cdn-learn.adafruit.com/downloads/pdf/adafruit-9-dof-orientation-imu-fusion-breakout-bno085.pdf
Capacitor | VJ0805Y103JXAAC | 10000 pF ±5% 50V Ceramic Capacitor X7R 0805 (2012 Metric) | 3 | 0.26 | https://www.digikey.com/en/products/detail/vishay-vitramon/VJ0805Y103JXAAC/8310931 | https://www.vishay.com/docs/45199/vjcommercialseries.pdf | Gyroscope Decoupling Capacitor
Capacitor | VJ0805Y474JXJTW1BC | 0.47 µF ±5% 16V Ceramic Capacitor X7R 0805 (2012 Metric) | 3 | 0.34 | https://www.digikey.com/en/products/detail/vishay-vitramon/VJ0805Y474JXJTW1BC/8312995 | https://www.vishay.com/docs/28548/vjw1bcbascomseries.pdf | Gyroscope Decoupling Capacitor
Motor | 2378 | 30:1 Micro Metal Gearmotor MP 6V with Extended Motor Shaft | 2 | 24.95 | https://www.pololu.com/product/2378
Encoder Pair | 4760 | Magnetic Encoder Pair Kit with Top-Entry Connector for Micro Metal Gearmotors, 12 CPR, 2.7-18V | 1 | 8.95 | https://www.pololu.com/product/4760
Motor Mount | 1086 | Pololu Micro Metal Gearmotor Bracket Pair - White | 1 | 2.95 | https://www.pololu.com/product/1086
Wheels | 1088 | Pololu Wheel 32×7mm Pair - White | 1 | 4.45 | https://www.pololu.com/product/1088
LiPo Battery | 258 | Lithium Ion Polymer Battery - 3.7v 1200mAh | 2 | 9.95 | https://www.adafruit.com/product/258
LiPo Battery Charger | 1304 | Adafruit Micro Lipo - USB LiIon/LiPoly charger - v2 | 1 | 5.95 | https://www.adafruit.com/product/1304
Socket | D01-9970642 | 6 (1 x 6) Pos SIP Socket Gold Through Hole | 3 | 0.63 | https://www.digikey.com/en/products/detail/harwin-inc/D01-9970642/3727951 | https://content.harwin.com/m/e0b6c35948424a73/original/DRG-00097-Technical-Drawing-Datasheet-D01-997-pdf.pdf | Socket for Gyroscope (https://content.harwin.com/m/e0b6c35948424a73/original/DRG-00097-Technical-Drawing-Datasheet-D01-997-pdf.pdf)
JST Connector | 4765 | JST SH-Style Cable for Micro Metal Gearmotor Encoders, 6-Pin, Female-Female, 10cm | 2 | 3.32 | https://www.pololu.com/product/4765

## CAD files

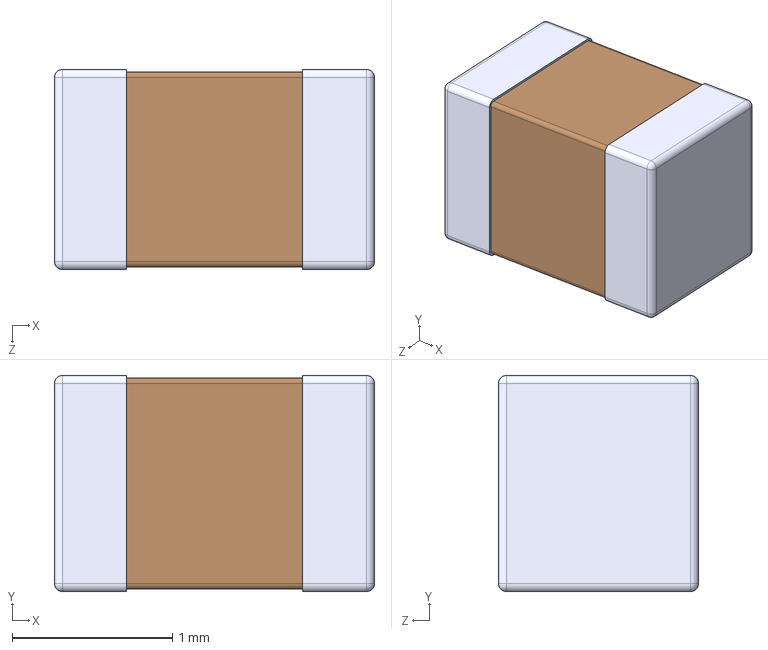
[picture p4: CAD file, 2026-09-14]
Micromouse_Parts/Assignment1B_PowerDelivery/10uF Capacitor (GRM21BR61C106KE15L)/GRM21BR61C106KE15L.step
2.00 x 1.35 x 1.25 mm

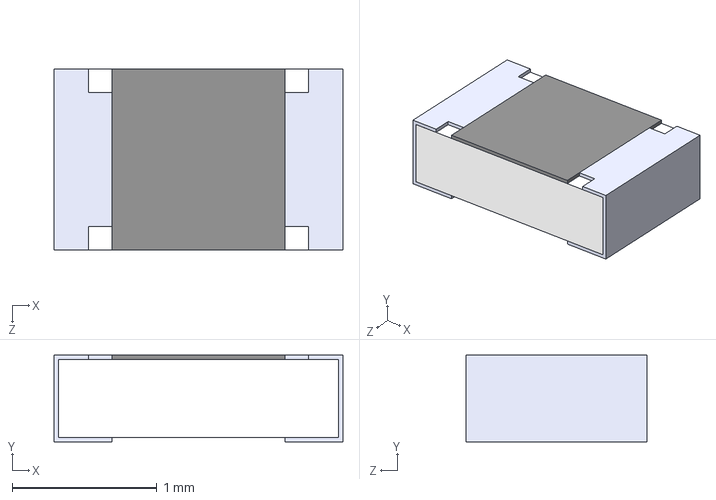
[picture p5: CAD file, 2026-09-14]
Micromouse_Parts/Assignment1B_PowerDelivery/200Ω Resistor (ERA_6AEB221V)/ERA6AEB221V.step
2.00 x 0.6 x 1.25 mm

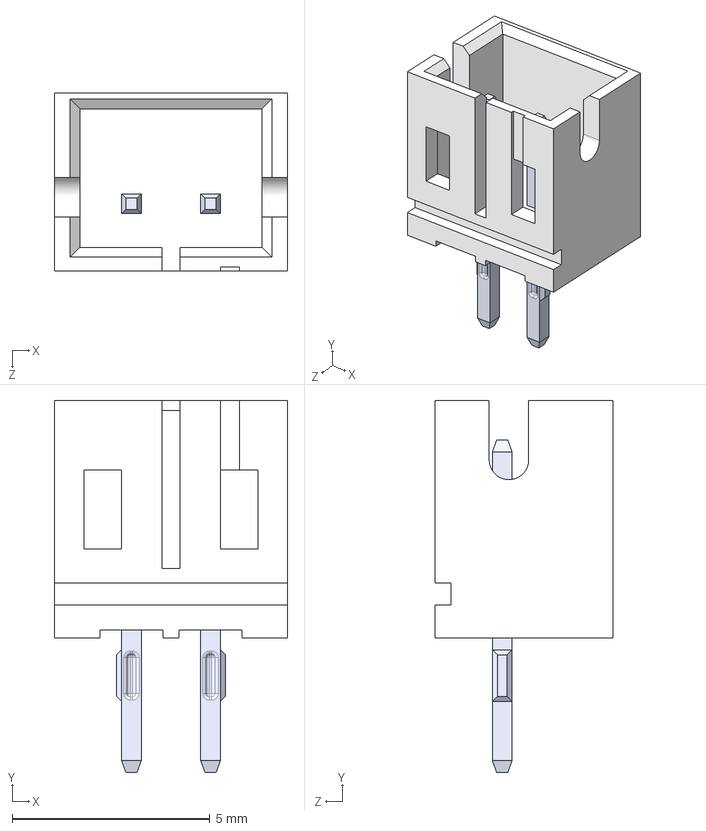
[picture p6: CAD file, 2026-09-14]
Micromouse_Parts/Assignment1B_PowerDelivery/JST Connector (B2B_PH_K_S)/B2B-PH-K-S.step
5.90 x 9.40 x 4.50 mm

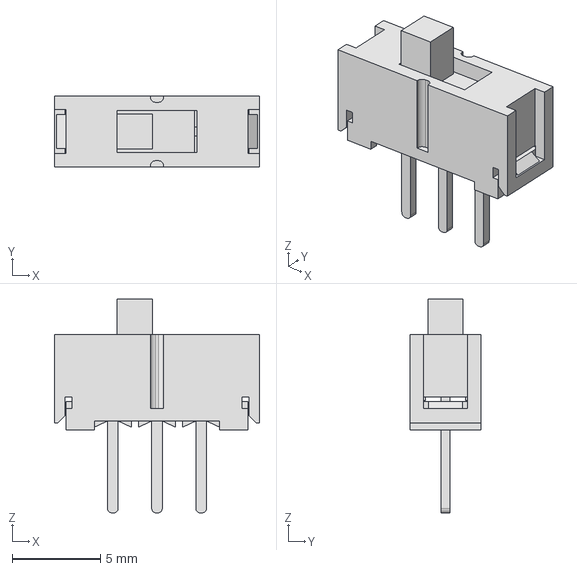
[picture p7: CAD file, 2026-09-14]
Micromouse_Parts/Assignment1B_PowerDelivery/Switch (EG1218)/EG1218.step
11.6 x 4.00 x 12.1 mm

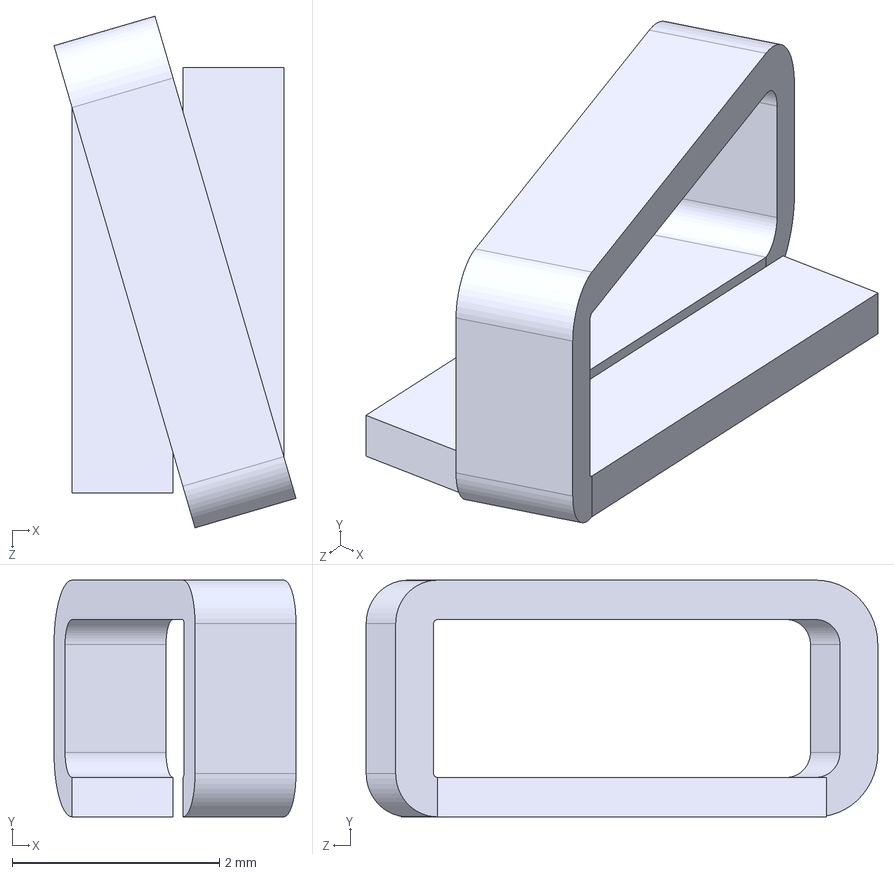
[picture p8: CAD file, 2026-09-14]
Micromouse_Parts/Assignment1B_PowerDelivery/Test Point (5095)/5095.step
2.34 x 2.29 x 4.94 mm

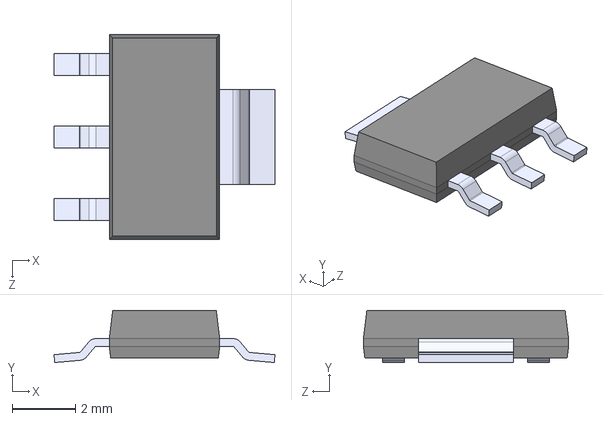
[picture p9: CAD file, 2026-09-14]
Micromouse_Parts/Assignment1B_PowerDelivery/Voltage Regulator (AZ1117IH-3.3TRG1)/AZ1117IH-3.3TRG1.step
7.00 x 1.65 x 6.50 mm

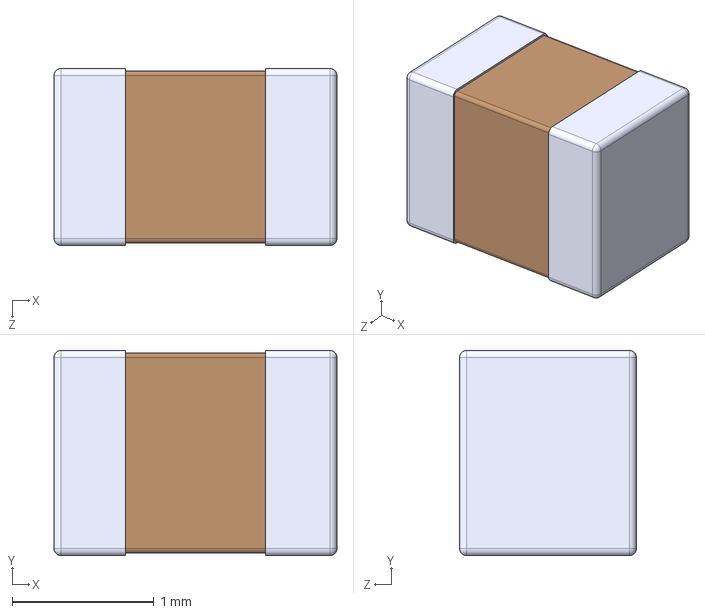
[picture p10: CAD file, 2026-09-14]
Micromouse_Parts/Assignment2B_MotorControl/0.1uF Capacitor (VJ0805Y104JXAAT)/VJ0805Y104JXAAT.step
2.00 x 1.45 x 1.25 mm

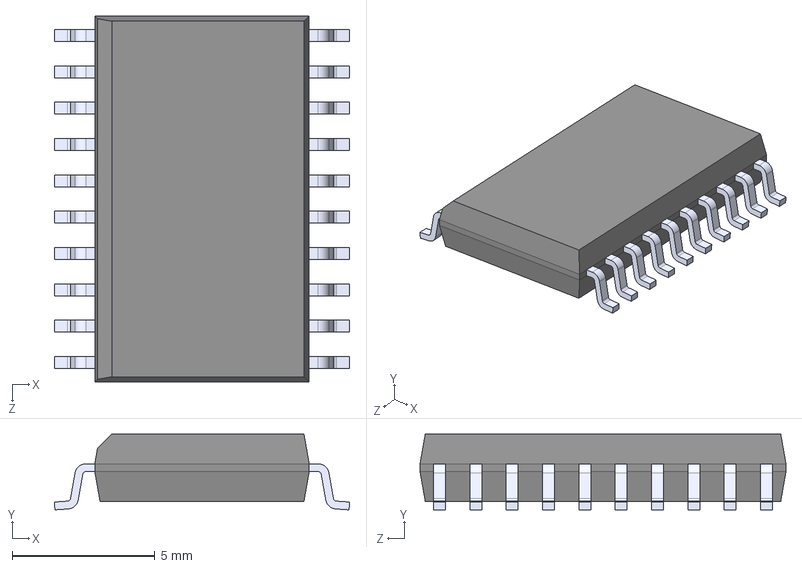
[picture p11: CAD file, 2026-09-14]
Micromouse_Parts/Assignment2B_MotorControl/H Bridge (L293DD)/L293DD.step
10.3 x 2.65 x 12.8 mm

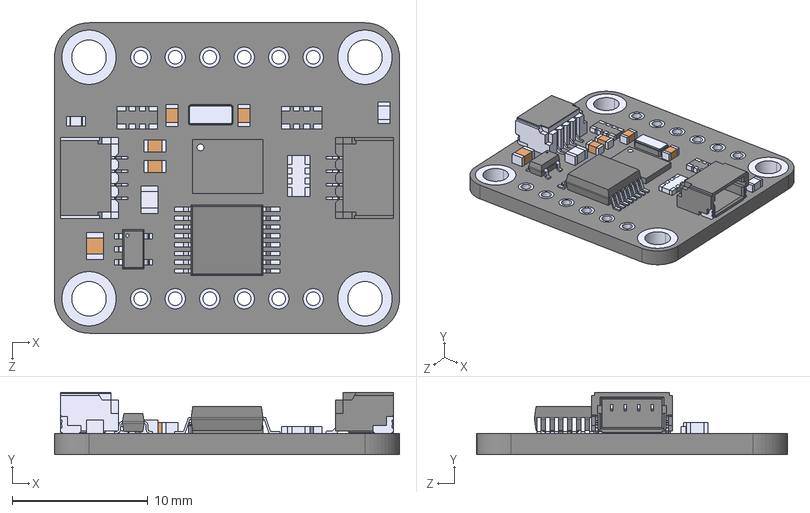
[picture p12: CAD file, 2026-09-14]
Micromouse_Parts/Gyroscope/Gyroscope Breakout (4754)/4754.step
25.4 x 4.60 x 22.9 mm
SPX5205M5
MAX4661CAE+

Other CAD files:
Micromouse_Parts/Assignment1B_PowerDelivery/22uF Capacitor (CL21A226KOQNNNE)/CL21A226KOQNNNE.step
Micromouse_Parts/Assignment2B_MotorControl/4.7uF Capacitor (GRT21BR61H475KE13L)/GRT21BR61H475KE13L.step
Micromouse_Parts/Assignment4B_IR/4.7uF Capacitor (GRT21BR61H475KE13L)/GRT21BR61H475KE13L.step
Micromouse_Parts/Microcontroller & Reset Button/1uF Capacitor (GRM21BC72A105KE01L)/GRM21BC72A105KE01L.step
Micromouse_Parts/Microcontroller & Reset Button/2.2uF Capacitor (GRM21BD72A225KE01L)/GRM21BD72A225KE01L.step
Micromouse_Parts/Microcontroller & Reset Button/STM32 (STM32F205RET7)/STM32F205RET7.step

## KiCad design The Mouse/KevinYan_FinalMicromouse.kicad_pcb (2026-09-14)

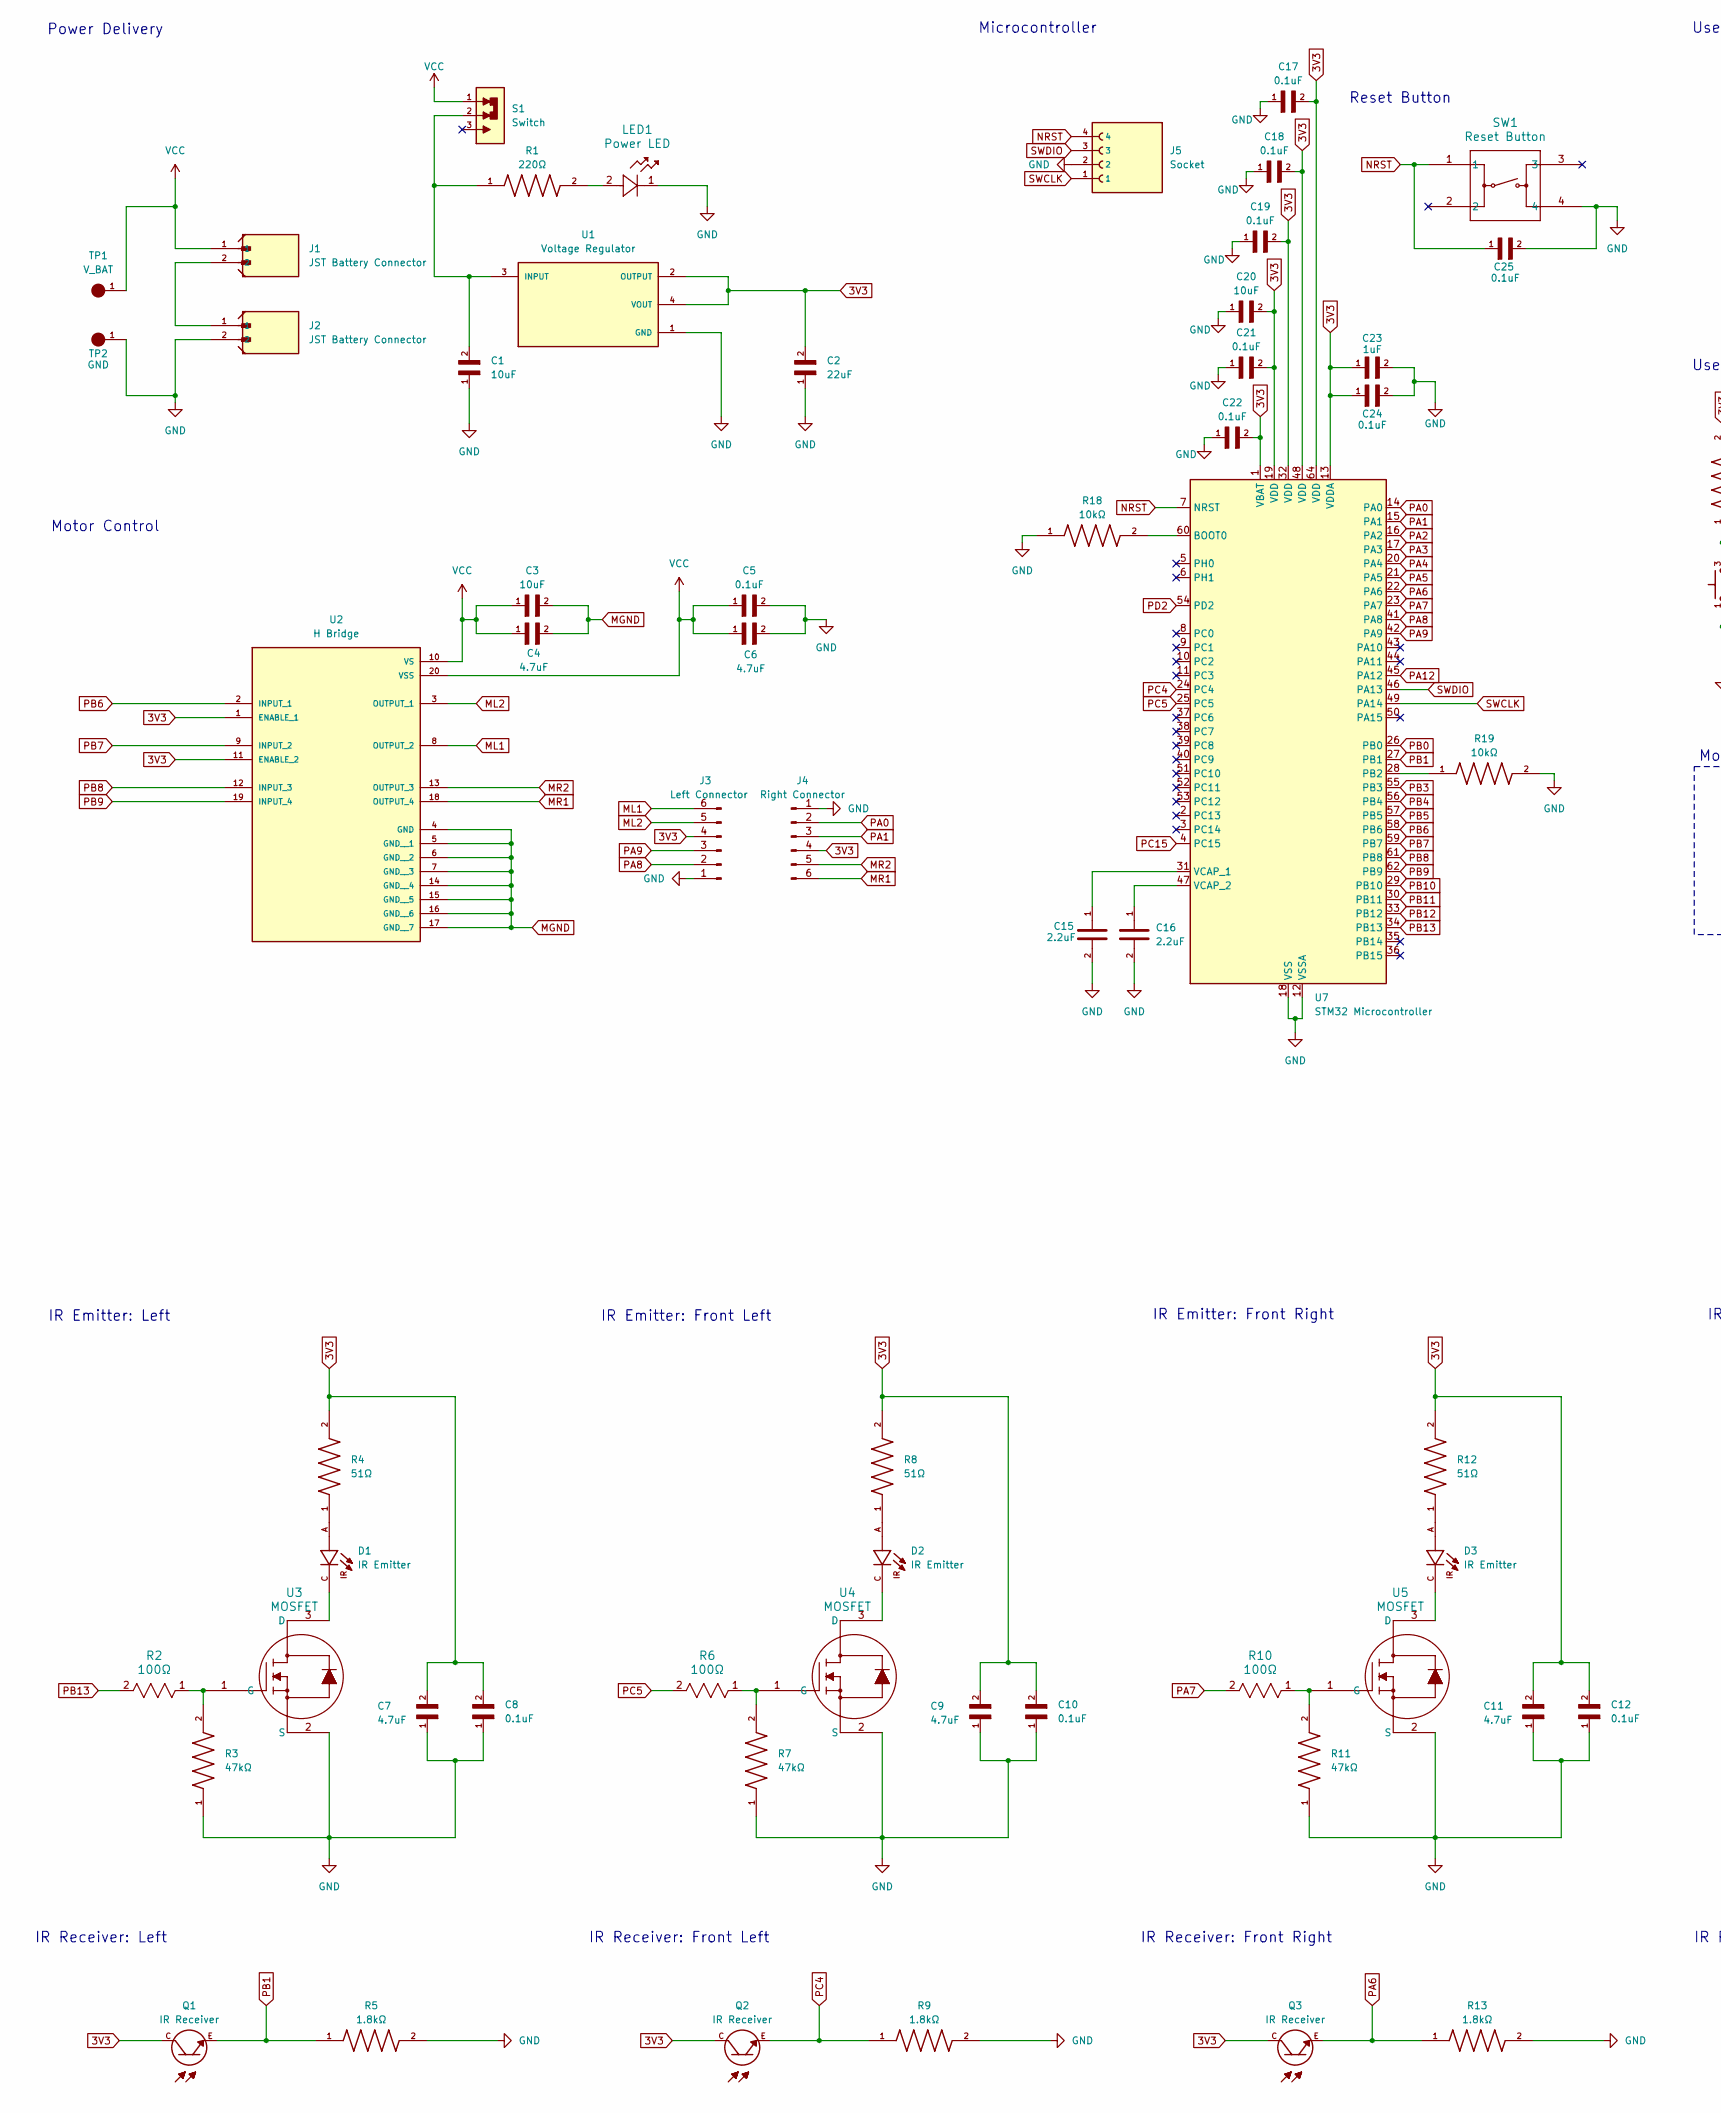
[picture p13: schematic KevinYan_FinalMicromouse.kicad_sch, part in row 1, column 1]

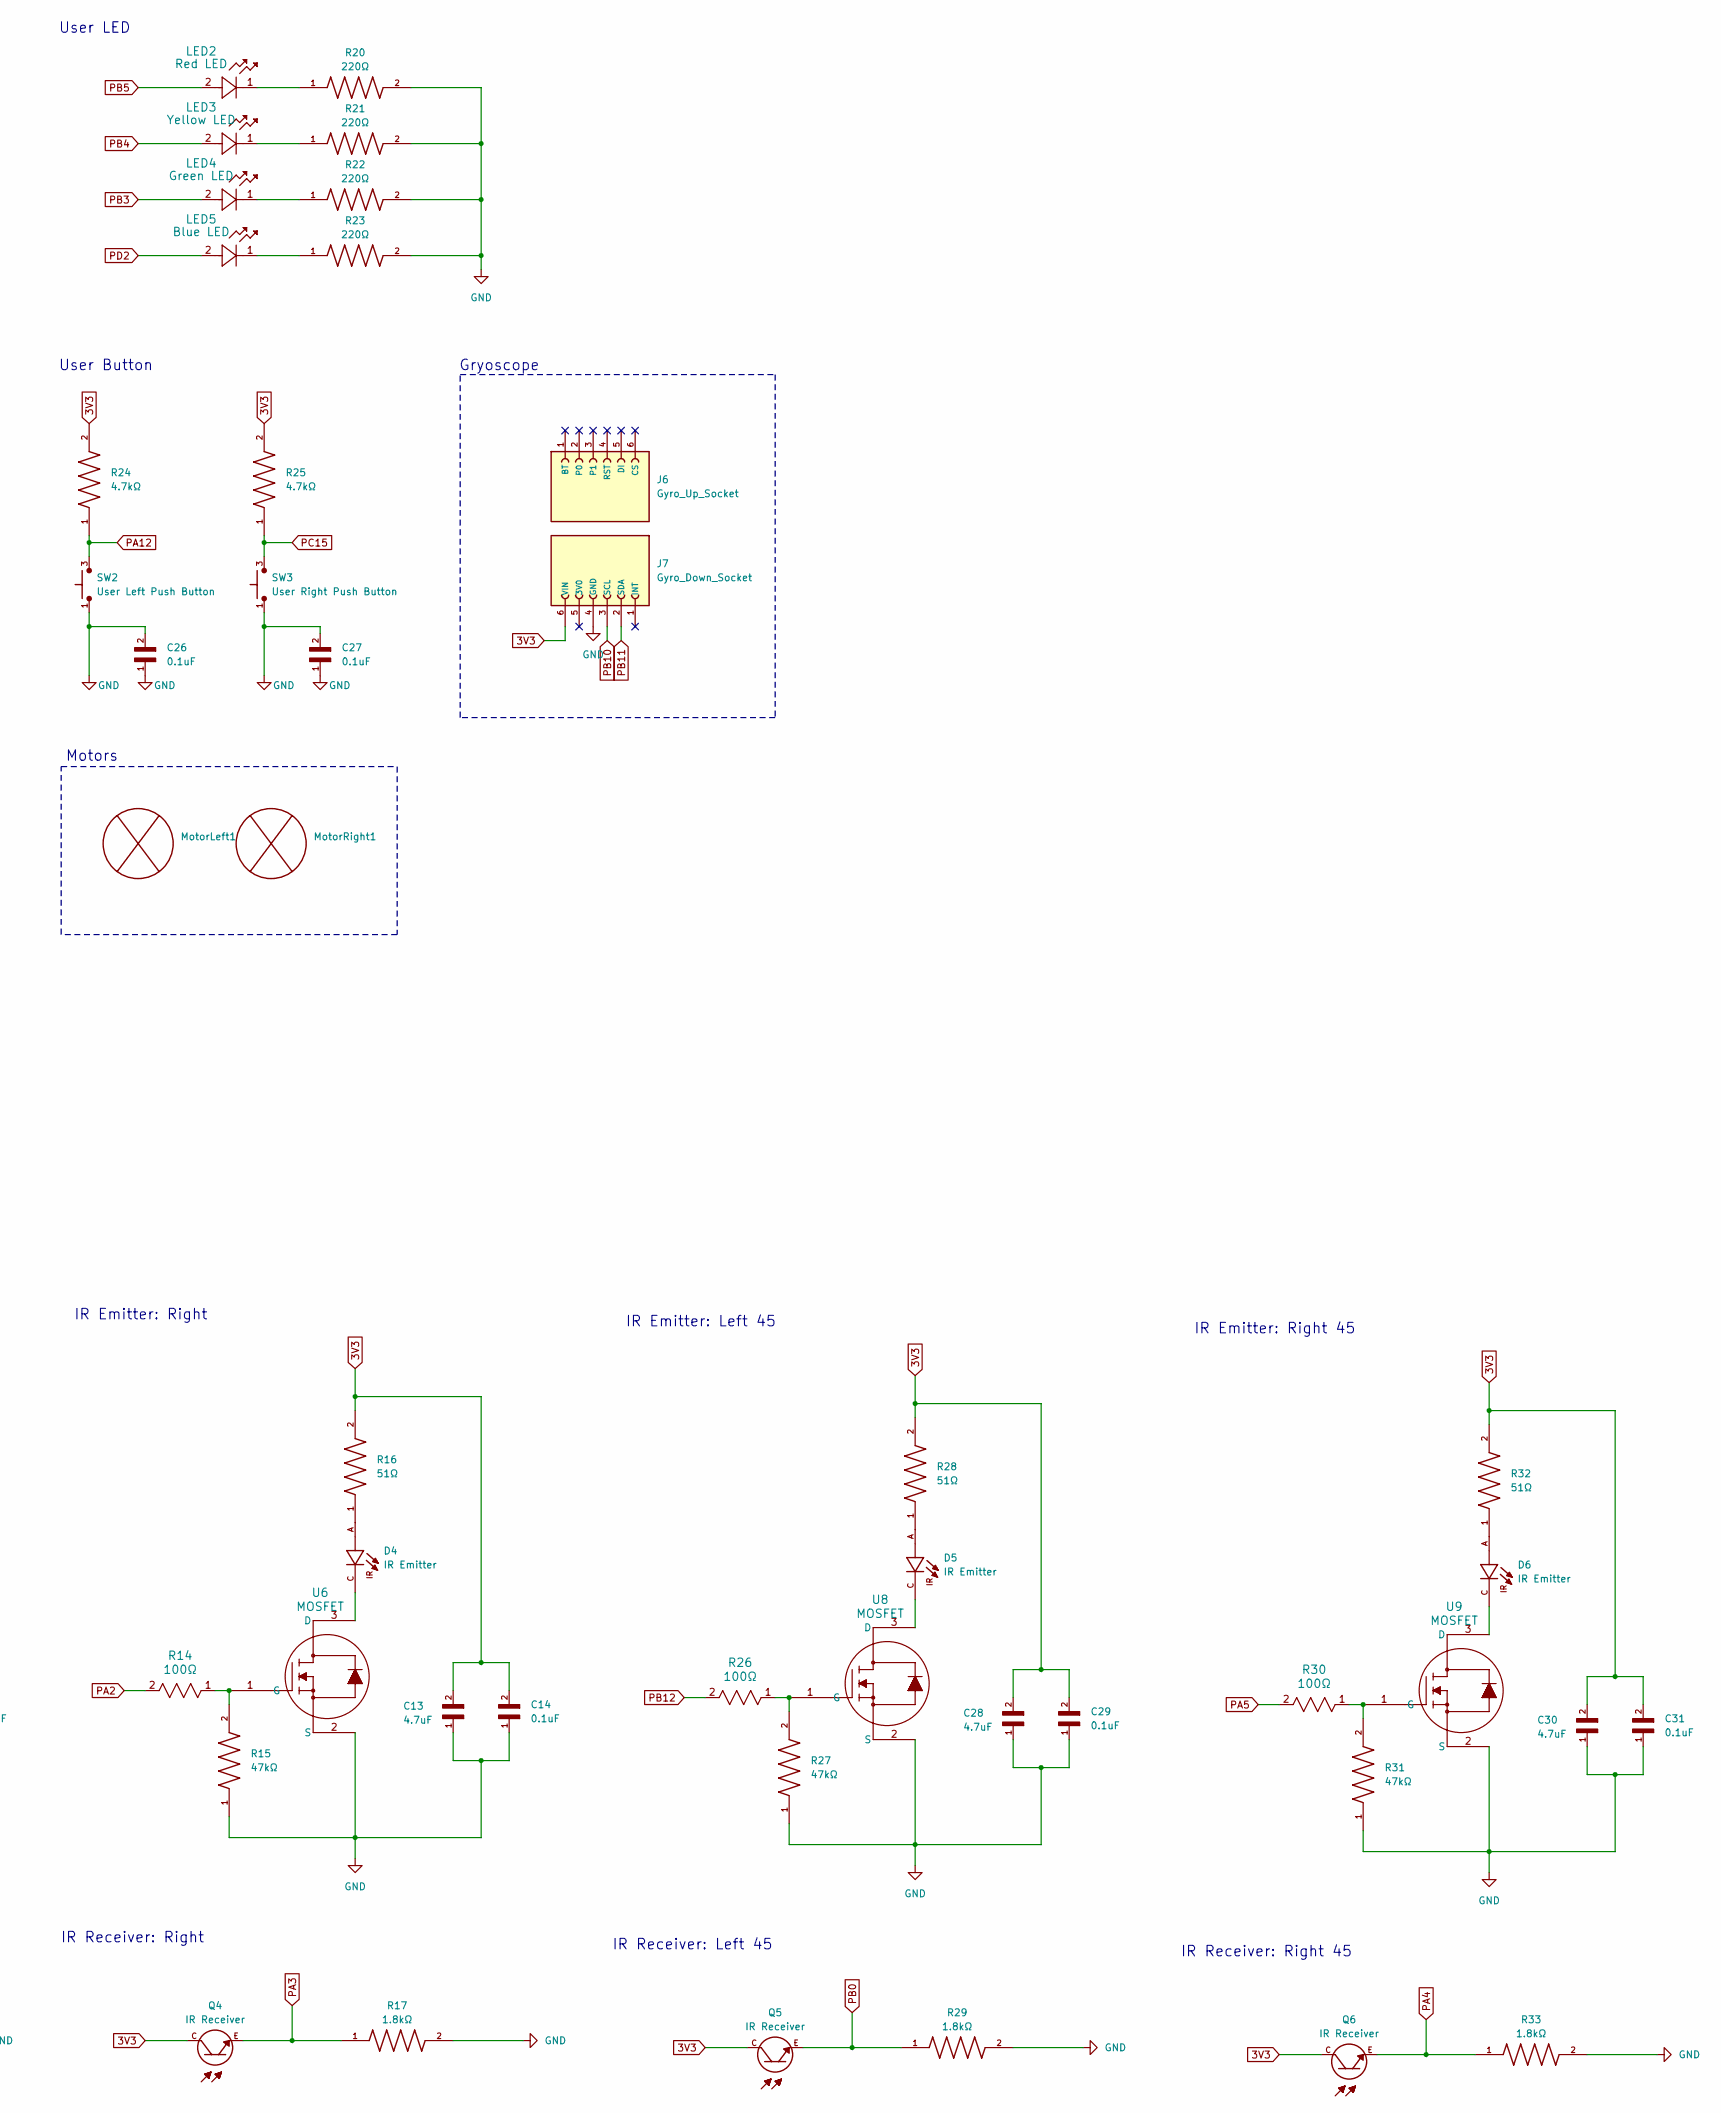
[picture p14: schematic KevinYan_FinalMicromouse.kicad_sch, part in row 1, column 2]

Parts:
C1, C3, C20: 10uF; CAPC2012X135N
C2: 22uF; CAPC2012X140N
C4, C6, C7, C9, C11, C13, C28, C30: 4.7uF; CAPC2012X140N
C5, C8, C10, C12, C14, C17, C18, C19, C21, C22, C24, C25, C26, C27, C29, C31: 0.1uF; CAPC2012X145N
C15, C16: 2.2uF; MURATA_GRM21BD72A225KE01L_0; DigiKey_Part_Number 490-GRM21BD72A225KE01LCT-ND
C23: 1uF; CAPC2012X145N; DigiKey_Part_Number 490-14464-1-ND
D1, D2, D3, D4, D5, D6: IR Emitter; DIO_VSMY2853SL; PARTREV 1.1
J1, J2: JST Battery Connector; JST_B2B-PH-K-S
J3: Left Connector; PinHeader_1x06_P2.54mm_Vertical
J4: Right Connector; PinHeader_1x06_P2.54mm_Vertical
J5: Socket; HARWIN_M22-7130442; DigiKey_Part_Number 952-1351-5-ND
J6: Gyro_Up_Socket; HARWIN_D01-9970642; DigiKey_Part_Number 952-1986-ND
J7: Gyro_Down_Socket; HARWIN_D01-9970642
LED1: Power LED; LED_LTST-C170GKT_LTO
LED2: Red LED; LED_LTST-C170GKT_LTO
LED3: Yellow LED; LED_LTST-C170GKT_LTO
LED4: Green LED; LED_LTST-C170GKT_LTO
LED5: Blue LED; LED_LTST-C170GKT_LTO
MotorLeft1: Pololu_Motor
MotorRight1: Pololu_Motor
Q1, Q2, Q3, Q4, Q5, Q6: IR Receiver; XDCR_VEMT2523SLX01
R1, R20, R21, R22, R23: 220Ω; RES_ERA6AEB221V; PARTREV 3/1/2020
R2, R6, R10, R14, R26, R30: 100Ω; RC0805N_PAN
R3, R7, R11, R15, R27, R31: 47kΩ; RES_ERA6AEB473V; PARTREV 3/1/2020
R4, R8, R12, R16, R28, R32: 51Ω; RES_ERA6AEB510V; PARTREV 3/1/2020
R5, R9, R13, R17, R29, R33: 1.8kΩ; RES_ERA6AEB182V; PARTREV 3/1/2020
R18, R19: 10kΩ; RESC2012X60N; DigiKey_Part_Number P10KDACT-ND
R24, R25: 4.7kΩ; RES_ERA6AEB473V; PARTREV 3/1/2020
S1: Switch; SW_EG1218
SW1: Reset Button; SPST_TR1_NDC
SW2: User Left Push Button; SW_KS11R23CQD; DigiKey_Part_Number CKN4082-ND
SW3: User Right Push Button; SW_KS11R23CQD; DigiKey_Part_Number CKN4082-ND
TP1: V_BAT; KEYSTONE_5095; DigiKey_Part_Number 36-5095CT-ND
TP2: GND; KEYSTONE_5095; DigiKey_Part_Number 36-5095CT-ND
U1: Voltage Regulator; SOT230P700X185-4N; PARTREV 2-2; DigiKey_Part_Number AZ1117IH-3.3TRG1DICT-ND
U2: H Bridge; SOIC127P1032X265-20N; PARTREV N/A
U3, U4, U5, U6, U8, U9: MOSFET; SOT-23_ONS
U7: STM32 Microcontroller; LQFP-64_10x10mm_P0.5mm

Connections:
3V3: C2.2, C7.2, C8.2, C9.2, C10.2, C11.2, C12.2, C13.2, C14.2, C17.2, C18.2, C19.2, C20.2, C21.2, C22.2, C23.1, C24.1, C28.2, C29.2, C30.2, C31.2, J3.4, J4.4, J7.6 (VIN), Q1.C, Q2.C, Q3.C, Q4.C, Q5.C, Q6.C, R4.2, R8.2, R12.2, R16.2, R24.2, R25.2, R28.2, R32.2, U1.2 (OUTPUT), U1.4 (VOUT), U2.1 (ENABLE_1), U2.11 (ENABLE_2), U7.1 (VBAT), U7.13 (VDDA), U7.19 (VDD), U7.32 (VDD), U7.48 (VDD), U7.64 (VDD)
GND: C1.1, C2.1, C5.2, C6.2, C7.1, C8.1, C9.1, C10.1, C11.1, C12.1, C13.1, C14.1, C15.2, C16.2, C17.1, C18.1, C19.1, C20.1, C21.1, C22.1, C23.2, C24.2, C25.2, C26.1, C26.2, C27.1, C27.2, C28.1, C29.1, C30.1, C31.1, J2.2, J3.1, J4.1, J5.2, J7.4 (GND), LED1.1, R3.1, R5.2, R7.1, R9.2, R11.1, R13.2, R15.1, R17.2, R18.1, R19.2, R20.2, R21.2, R22.2, R23.2, R27.1, R29.2, R31.1, R33.2, SW1.4, SW2.1, SW3.1, TP2.1, U1.1 (GND), U3.2 (S), U4.2 (S), U5.2 (S), U6.2 (S), U7.12 (VSSA), U7.18 (VSS), U7.63 (VSS), U8.2 (S), U9.2 (S)
MGND: C3.2, C4.2, U2.4 (GND), U2.5 (GND__1), U2.6 (GND__2), U2.7 (GND__3), U2.14 (GND__4), U2.15 (GND__5), U2.16 (GND__6), U2.17 (GND__7)
ML1: J3.6, U2.8 (OUTPUT_2)
ML2: J3.5, U2.3 (OUTPUT_1)
MR1: J4.6, U2.18 (OUTPUT_4)
MR2: J4.5, U2.13 (OUTPUT_3)
NRST: C25.1, J5.4, SW1.1, U7.7 (NRST)
unnamed: D1.A, R4.1
unnamed: D2.A, R8.1
unnamed: D3.A, R12.1
unnamed: D4.A, R16.1
unnamed: D5.A, R28.1
unnamed: D6.A, R32.1
unnamed: J1.2, J2.1
unnamed: LED1.2, R1.2
unnamed: LED2.1, R20.1
unnamed: LED3.1, R21.1
unnamed: LED4.1, R22.1
unnamed: LED5.1, R23.1
unnamed: C1.2, R1.1, S1.2, U1.3 (INPUT)
unnamed: D1.C, U3.3 (D)
unnamed: R2.1, R3.2, U3.1 (G)
unnamed: D2.C, U4.3 (D)
unnamed: R6.1, R7.2, U4.1 (G)
unnamed: D3.C, U5.3 (D)
unnamed: R10.1, R11.2, U5.1 (G)
unnamed: D4.C, U6.3 (D)
unnamed: R14.1, R15.2, U6.1 (G)
unnamed: R18.2, U7.60 (BOOT0)
unnamed: R19.1, U7.28 (PB2)
unnamed: C15.1, U7.31 (VCAP_1)
unnamed: C16.1, U7.47 (VCAP_2)
unnamed: D5.C, U8.3 (D)
unnamed: R26.1, R27.2, U8.1 (G)
unnamed: D6.C, U9.3 (D)
unnamed: R30.1, R31.2, U9.1 (G)
PA0: J4.2, U7.14 (PA0)
PA1: J4.3, U7.15 (PA1)
PA2: R14.2, U7.16 (PA2)
PA3: Q4.E, R17.1, U7.17 (PA3)
PA4: Q6.E, R33.1, U7.20 (PA4)
PA5: R30.2, U7.21 (PA5)
PA6: Q3.E, R13.1, U7.22 (PA6)
PA7: R10.2, U7.23 (PA7)
PA8: J3.2, U7.41 (PA8)
PA9: J3.3, U7.42 (PA9)
PA12: R24.1, SW2.3, U7.45 (PA12)
PB0: Q5.E, R29.1, U7.26 (PB0)
PB1: Q1.E, R5.1, U7.27 (PB1)
PB3: LED4.2, U7.55 (PB3)
PB4: LED3.2, U7.56 (PB4)
PB5: LED2.2, U7.57 (PB5)
PB6: U2.2 (INPUT_1), U7.58 (PB6)
PB7: U2.9 (INPUT_2), U7.59 (PB7)
PB8: U2.12 (INPUT_3), U7.61 (PB8)
PB9: U2.19 (INPUT_4), U7.62 (PB9)
PB10: J7.3 (SCL), U7.29 (PB10)
PB11: J7.2 (SDA), U7.30 (PB11)
PB12: R26.2, U7.33 (PB12)
PB13: R2.2, U7.34 (PB13)
PC4: Q2.E, R9.1, U7.24 (PC4)
PC5: R6.2, U7.25 (PC5)
PC15: R25.1, SW3.3, U7.4 (PC15)
PD2: LED5.2, U7.54 (PD2)
SWCLK: J5.1, U7.49 (PA14)
SWDIO: J5.3, U7.46 (PA13)
VCC: C3.1, C4.1, C5.1, C6.1, J1.1, S1.1, TP1.1, U2.10 (VS), U2.20 (VSS)

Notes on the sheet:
IR Emitter: Front Right
Microcontroller
Motor Control
IR Receiver: Front Right
Motors
IR Emitter: Right 45
IR Receiver: Left 45
IR Emitter: Front Left
IR Receiver: Left
IR Emitter: Right
User LED
IR Receiver: Front Left
IR Receiver: Right 45
Reset Button
Power Delivery
User Button
Gryoscope
IR Emitter: Left
IR Receiver: Right
IR Emitter: Left 45

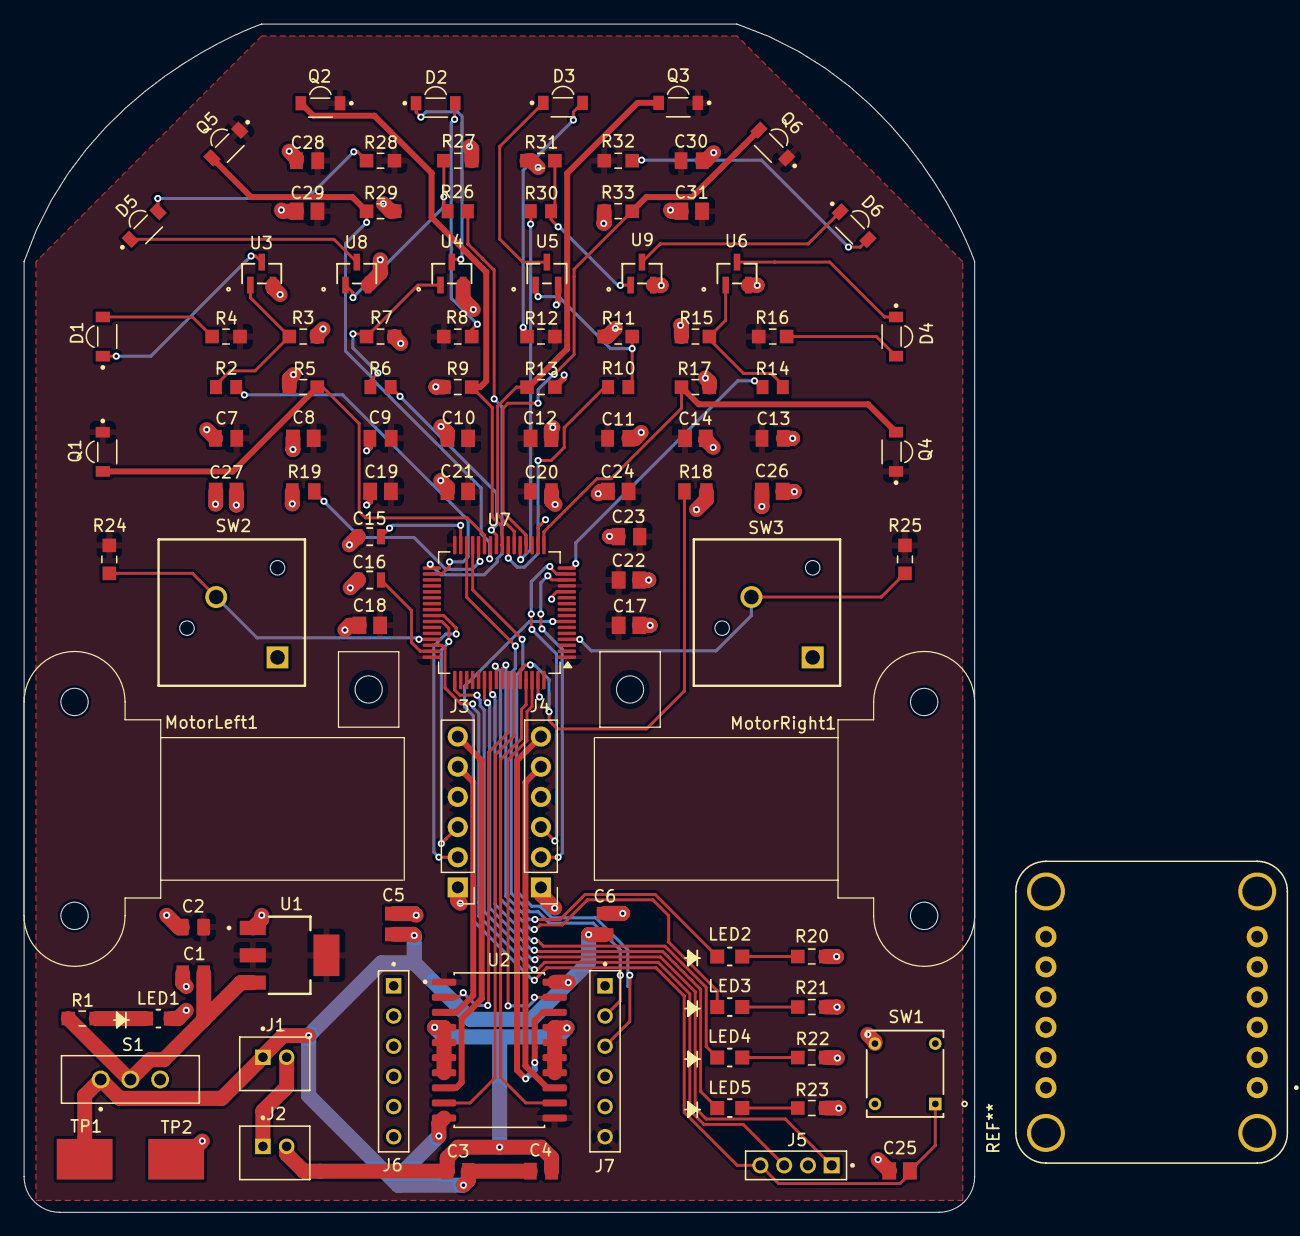
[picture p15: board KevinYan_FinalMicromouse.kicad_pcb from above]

Board: 2 copper layers, 80.0 x 100.0 mm, 105 parts (0 on the bottom side), 68 nets.

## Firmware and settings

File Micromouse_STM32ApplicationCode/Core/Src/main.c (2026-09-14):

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
/* Includes ------------------------------------------------------------------*/
#include "main.h"

/* USER CODE BEGIN Includes */
#include "encoders.h"
#include "motors.h"
#include "delay.h"
#include "irs.h"
#include "pid.h"
#include "controller.h"
#include "gyroscope.h"
#include "solver.h"
#include <math.h>
/* USER CODE END Includes */

/* USER CODE BEGIN PD */
#define BNO085_I2C_ADDR (0x4A << 1)
/* USER CODE END PD */

ADC_HandleTypeDef hadc1;
DMA_HandleTypeDef hdma_adc1;

I2C_HandleTypeDef hi2c2;

TIM_HandleTypeDef htim1;
TIM_HandleTypeDef htim2;
TIM_HandleTypeDef htim4;

/* USER CODE BEGIN PV */
int16_t left_counts = 0;
int16_t right_counts = 0;

int16_t IR_counts_l = 0;
int16_t IR_counts_45l = 0;
int16_t IR_counts_fl = 0;
int16_t IR_counts_fr = 0;
int16_t IR_counts_45r = 0;
int16_t IR_counts_r = 0;

int16_t wallLeft = -1;
int16_t wallFront = -1;
int16_t wallRight = -1;

int isTraversing = 1;
int correctionCounter = 0;

BNO085_t mouse_imu;

volatile float current_yaw = 0.0f; // Your crucial turning variable (Yaw)
volatile float current_pitch = 0.0f;   // Useful to check if the mouse is popping a wheelie
volatile float current_roll = 0.0f;

volatile float initial_yaw = 0.0f;

//volatile uint16_t debug_packet_length = 0;
//volatile uint8_t  debug_channel = 0;
//volatile uint8_t  debug_report_id = 0;

/* USER CODE END PV */

void SystemClock_Config(void);
static void MX_GPIO_Init(void);
static void MX_DMA_Init(void);
static void MX_ADC1_Init(void);
static void MX_TIM1_Init(void);
static void MX_TIM2_Init(void);
static void MX_TIM4_Init(void);
static void MX_I2C2_Init(void);
/**
  * @brief  The application entry point.
  * @retval int
  */
int main(void)
{

  /* MCU Configuration--------------------------------------------------------*/

  /* Reset of all peripherals, Initializes the Flash interface and the Systick. */
  HAL_Init();

  /* USER CODE BEGIN Init */
  Delay_Init();
  /* USER CODE END Init */

  /* Configure the system clock */
  SystemClock_Config();

  /* Initialize all configured peripherals */
  MX_GPIO_Init();
  MX_DMA_Init();
  MX_ADC1_Init();
  MX_TIM1_Init();
  MX_TIM2_Init();
  MX_TIM4_Init();
  MX_I2C2_Init();
  /* USER CODE BEGIN 2 */
  HAL_TIM_Encoder_Start(&htim1, TIM_CHANNEL_ALL);
  HAL_TIM_Encoder_Start(&htim2, TIM_CHANNEL_ALL);

  HAL_TIM_PWM_Start(&htim4, TIM_CHANNEL_1);
  HAL_TIM_PWM_Start(&htim4, TIM_CHANNEL_2);
  HAL_TIM_PWM_Start(&htim4, TIM_CHANNEL_3);
  HAL_TIM_PWM_Start(&htim4, TIM_CHANNEL_4);

  HAL_Delay(1000);

  BNO085_Init(&mouse_imu, &hi2c2, BNO085_I2C_ADDR);

  HAL_Delay(100);

  // 3. Pump the update loop for 500ms to guarantee a fresh, valid I2C data packet arrives
  uint32_t start_boot_sync = HAL_GetTick();
  while (HAL_GetTick() - start_boot_sync < 500) {
      BNO085_Update(&mouse_imu);
      HAL_Delay(5);
  }

  // 4. Snap the baseline! This direction is now officially 0.0 degrees.
  initial_yaw = BNO085_GetAngle(&mouse_imu, ANGLE_YAW);

  HAL_Delay(2000);
  //stupidPath();

  /* USER CODE END 2 */

  /* Infinite loop */
  /* USER CODE BEGIN WHILE */
  while (1)
  {
	  left_counts = getLeftEncoderCounts();
	  right_counts = getRightEncoderCounts();

	  IR_counts_l = readIR (IR_LEFT);
	  IR_counts_45l = readIR (IR_LEFT45);
	  IR_counts_fl = readIR (IR_FRONT_LEFT);
	  IR_counts_fr = readIR (IR_FRONT_RIGHT);
	  IR_counts_45r = readIR (IR_RIGHT45);
	  IR_counts_r = readIR (IR_RIGHT);

	  wallLeft = isWallLeft();
	  wallFront = isWallFront();
	  wallRight = isWallRight();


    /* USER CODE END WHILE */

    /* USER CODE BEGIN 3 */

	  BNO085_Update(&mouse_imu);
	  //continue;

//	  current_yaw   = BNO085_GetAngle(&mouse_imu, ANGLE_YAW);
//	  current_pitch = BNO085_GetAngle(&mouse_imu, ANGLE_PITCH);
//	  current_roll  = BNO085_GetAngle(&mouse_imu, ANGLE_ROLL);

	  if (isTraversing == 0){
		  if (HAL_GPIO_ReadPin(LeftButton_GPIO_Port, LeftButton_Pin) == GPIO_PIN_RESET && isTraversing == 0){
			  HAL_GPIO_WritePin(RedLED_GPIO_Port, RedLED_Pin, GPIO_PIN_RESET);
			  HAL_Delay(1000);
			  isTraversing = 1;
			  refresh();
			  resetRobotPos();
			  HAL_Delay(1000);

			  BNO085_Update(&mouse_imu);
			  initial_yaw = BNO085_GetAngle(&mouse_imu, ANGLE_YAW);
			  setPIDGoalA(0);
			  HAL_Delay(2000);
		  }

		  if (HAL_GPIO_ReadPin(RightButton_GPIO_Port, RightButton_Pin) == GPIO_PIN_RESET && isTraversing == 0){
			  HAL_GPIO_WritePin(BlueLED_GPIO_Port, BlueLED_Pin, GPIO_PIN_SET);

			  char* speedRunPath = getOptimalPath();
			  int index = 0;

			  HAL_Delay(1000);
			  refresh();
			  resetRobotPos();
			  HAL_Delay(1000);

			  BNO085_Update(&mouse_imu);
			  initial_yaw = BNO085_GetAngle(&mouse_imu, ANGLE_YAW);
			  setPIDGoalA(0);
			  correctionCounter = 0;
			  HAL_Delay(2000);
			  while (speedRunPath[index] != '\0') {

				  if (speedRunPath[index] == 'f') {
					  int forwardCount = 0;

					  // Look ahead and count how many 'f's are in a row
					  while (speedRunPath[index] == 'f') {
						  forwardCount++;
						  index++; // Advance the main string index
					  }

					  // Execute the consolidated move
					  if (forwardCount <= 7)
						  move(forwardCount);
					  else{
						  move (7);
						  move (forwardCount - 7);
					  }
				  }
				  else if (speedRunPath[index] == 'l') {
					  turn(-90);
					  index++;
				  }
				  else if (speedRunPath[index] == 'r') {
					  turn(90);
					  index++;
				  }
				  else {
					  // Failsafe to prevent infinite loops if an invalid char sneaks in
					  index++;
				  }
			  }
			  HAL_GPIO_WritePin(BlueLED_GPIO_Port, BlueLED_Pin, GPIO_PIN_RESET);
		  }

		  continue;
	  }
	  // --- LEFT BUTTON LOGIC ---
	  // If the Left Button is pushed (reads LOW / GPIO_PIN_RESET)
//	  if (HAL_GPIO_ReadPin(LeftButton_GPIO_Port, LeftButton_Pin) == GPIO_PIN_RESET)
//	  {
//	      // Turn ON Red and Yellow LEDs
//	      HAL_GPIO_WritePin(RedLED_GPIO_Port, RedLED_Pin, GPIO_PIN_SET);
//	      HAL_GPIO_WritePin(YellowLED_GPIO_Port, YellowLED_Pin, GPIO_PIN_SET);
//	      setMotorLPWM(0.5);
//	  }
//	  else
//	  {
//	      // Turn OFF Red and Yellow LEDs
//	      HAL_GPIO_WritePin(RedLED_GPIO_Port, RedLED_Pin, GPIO_PIN_RESET);
//	      HAL_GPIO_WritePin(YellowLED_GPIO_Port, YellowLED_Pin, GPIO_PIN_RESET);
//	      setMotorLPWM(0);
//	  }
//
//	  // --- RIGHT BUTTON LOGIC ---
//	  // If the Right Button is pushed (reads LOW / GPIO_PIN_RESET)
//	  if (HAL_GPIO_ReadPin(RightButton_GPIO_Port, RightButton_Pin) == GPIO_PIN_RESET)
//	  {
//	      // Turn ON Green and Blue LEDs
//	      HAL_GPIO_WritePin(GreenLED_GPIO_Port, GreenLED_Pin, GPIO_PIN_SET);
//	      HAL_GPIO_WritePin(BlueLED_GPIO_Port, BlueLED_Pin, GPIO_PIN_SET);
//	      setMotorRPWM(0.5);
//	  }
//	  else
//	  {
//	      // Turn OFF Green and Blue LEDs
//	      HAL_GPIO_WritePin(GreenLED_GPIO_Port, GreenLED_Pin, GPIO_PIN_RESET);
//	      HAL_GPIO_WritePin(BlueLED_GPIO_Port, BlueLED_Pin, GPIO_PIN_RESET);
//	      setMotorRPWM(0);
//	  }


	  Action nextMove = solver();
	  switch(nextMove){
		  case FORWARD:
			  move(1);
			  break;
		  case LEFT:
			  turn(-90);
			  break;
		  case RIGHT:
			  turn(90);
			  break;
		  case IDLE:
			  break;
	  }

	  if (isWallFront() && (correctionCounter >= CORRECTIONCOUNT)){
		  adjustment();
	  }
  }

  /* USER CODE END 3 */
}

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
/* USER CODE BEGIN 4 */
ADC_HandleTypeDef* Get_HADC1_Ptr(void)
{
	return &hadc1;
}


/* USER CODE END 4 */
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


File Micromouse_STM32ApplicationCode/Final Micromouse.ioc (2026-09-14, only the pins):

Mcu.UserName=STM32F205RETx
PA0-WKUP.GPIO_Label=RightEncoderCh1
PA0-WKUP.Signal=S_TIM2_CH1_ETR
PA1.GPIO_Label=RightEncoderCh2
PA1.Signal=S_TIM2_CH2
PA12.GPIO_Label=LeftButton
PA12.Signal=GPIO_Input
PA2.GPIO_Label=RightEmitter
PA2.Signal=GPIO_Output
PA3.GPIO_Label=RightReceiver
PA3.Signal=ADCx_IN3
PA4.GPIO_Label=Right45Receiver
PA4.Signal=ADCx_IN4
PA5.GPIO_Label=Right45Emitter
PA5.Signal=GPIO_Output
PA6.GPIO_Label=FrontRightReceiver
PA6.Signal=ADCx_IN6
PA7.GPIO_Label=FrontRightEmitter
PA7.Signal=GPIO_Output
PA8.GPIO_Label=LeftEncoderCh1
PA8.Signal=S_TIM1_CH1
PA9.GPIO_Label=LeftEncoderCh2
PA9.Signal=S_TIM1_CH2
PB0.GPIO_Label=Left45Receiver
PB0.Signal=ADCx_IN8
PB1.GPIO_Label=LeftReceiver
PB1.Signal=ADCx_IN9
PB10.GPIO_Label=I2C_SCL_Gyro
PB10.Signal=I2C2_SCL
PB11.GPIO_Label=I2C_SDA_Gyro
PB11.Signal=I2C2_SDA
PB12.GPIO_Label=Left45Emitter
PB12.Signal=GPIO_Output
PB13.GPIO_Label=LeftEmitter
PB13.Signal=GPIO_Output
PB3.GPIO_Label=GreenLED
PB3.Signal=GPIO_Output
PB4.GPIO_Label=YellowLED
PB4.Signal=GPIO_Output
PB5.GPIO_Label=RedLED
PB5.Signal=GPIO_Output
PB6.GPIO_Label=MotorCh1
PB6.Signal=S_TIM4_CH1
PB7.GPIO_Label=MotorCh2
PB7.Signal=S_TIM4_CH2
PB8.GPIO_Label=MotorCh3
PB8.Signal=S_TIM4_CH3
PB9.GPIO_Label=MotorCh4
PB9.Signal=S_TIM4_CH4
PC15-OSC32_OUT.GPIO_Label=RightButton
PC15-OSC32_OUT.Signal=GPIO_Input
PC4.GPIO_Label=FrontLeftReceiver
PC4.Signal=ADCx_IN14
PC5.GPIO_Label=FrontLeftEmitter
PC5.Signal=GPIO_Output
PD2.GPIO_Label=BlueLED
PD2.Signal=GPIO_Output

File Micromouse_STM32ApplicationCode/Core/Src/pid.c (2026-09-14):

/*
 * pid.c
 */

#include "main.h"
#include "motors.h"
#include "encoders.h"
#include "delay.h"
#include "gyroscope.h"

// --- Tuning Parameters (adjust these) ---
#define KPW         0.0087   // Angle proportional 0.008, Works good: 0.009 Works even better: 0.0087
#define KDW         0.09    // Angle derivative 0.055, Works good: 0.065 Works even better:0.063

#define KIW         0.00005f         // Start incredibly small! It compounds 1000x a second. //0.0001
#define MAX_I_TERM  0.250f    // The absolute maximum PWM the I-term is allowed to contribute //0.15

//KDW 0.055
#define KPD         0.002  // Distance proportional
#define KDD         0.0063   // Distance derivative
#define DIST_THRESH 30       // Encoder counts "close enough" to goal originally: 25
#define ANG_THRESH  7		// Originally: 10
#define DONE_CYCLES 20     // Must be stable for this many cycles Originally: 50

// --- Acceleration Parameters ---
#define MIN_START_SPD   0.15f   // Minimum PWM to overcome motor friction
#define MAX_SPD         1.0f
#define MAX_TURN_SPD    0.8f    // Maximum cruise speed for pure turning
#define ACCEL_DIST      0.005f  // Add 0.005 PWM every 1ms for distance
#define ACCEL_ANGLE     0.01f   // Add 0.01 PWM every 1ms for turning

// --- Speed Limit State Variables ---
static float currentDistSpeedLimit  = MIN_START_SPD;
static float currentAngleSpeedLimit = MIN_START_SPD;

// --- Global Variables ---
extern BNO085_t mouse_imu;
extern volatile float initial_yaw;

// --- Goal Variables ---
static int32_t goalDistance = 0;
static float   goalAngle    = 0.0f;

// --- Error Variables ---
static float angleError       = 0;
static float oldAngleError    = 0;
static float distanceError    = 0;
static float oldDistanceError = 0;
static float angleErrorSum    = 0.0f;

// --- Done Tracking ---
static int     stableCount = 0;
static int8_t  isDone      = 0;

// --- SysTick Flag ---
static volatile uint8_t pidRunning = 0;

// -------------------------------------------------------

uint8_t getPidRunning(void)
{
    return pidRunning;
}

void resetPID()
{
    goalDistance     = 0;
    //goalAngle        = 0;
    angleError       = 0;
    oldAngleError    = 0;
    distanceError    = 0;
    oldDistanceError = 0;
    stableCount      = 0;
    isDone           = 0;

    setMotorLPWM(0);
    setMotorRPWM(0);
    resetEncoders();

    // Reset acceleration limits!
    currentDistSpeedLimit  = MIN_START_SPD;
    currentAngleSpeedLimit = MIN_START_SPD;

    angleErrorSum = 0.0f;
}

void setPIDGoalD(int16_t distance)
{
    goalDistance = distance;
    currentDistSpeedLimit = MIN_START_SPD;
}

void setPIDGoalA(int16_t angle)
{
	goalAngle = initial_yaw + (float)angle;
	currentAngleSpeedLimit = MIN_START_SPD;
}

void updatePID()
{
    int32_t leftCounts  = getLeftEncoderCounts();
    int32_t rightCounts = getRightEncoderCounts();
    int32_t avgCounts   = (leftCounts + rightCounts) / 2;

    // Get live world telemetry
    float currentYaw = BNO085_GetAngle(&mouse_imu, ANGLE_YAW);

    // --- Angle Error ---
    oldAngleError = angleError;
    angleError    = currentYaw - goalAngle;

    // --- Distance Error ---
    oldDistanceError = distanceError;
    distanceError    = (float)(goalDistance - avgCounts);

    // Normalize error boundary loop (-180 to +180)
    // This calculates the shortest steering rotation to hit the relative goal
    while (angleError > 180.0f)  angleError -= 360.0f;
    while (angleError < -180.0f) angleError += 360.0f;

    // --- PD Corrections ---
    float dAngleError = angleError - oldAngleError;

    // Normalize the derivative boundary loop so the math never spikes across the 180 line
    while (dAngleError > 180.0f)  dAngleError -= 360.0f;
    while (dAngleError < -180.0f) dAngleError += 360.0f;

    angleErrorSum += angleError;
	// Calculate what the I-term's PWM contribution currently is
	float i_term_pwm = KIW * angleErrorSum;

	// If it exceeds our safety limit, clamp the sum itself
	if (i_term_pwm > MAX_I_TERM) {
		angleErrorSum = MAX_I_TERM / KIW;
	} else if (i_term_pwm < -MAX_I_TERM) {
		angleErrorSum = -MAX_I_TERM / KIW;
	}

	// Optional but highly recommended: Zero the integral if we cross the target
	// to prevent overshooting caused by old accumulated error
	if ((angleError > 0 && oldAngleError < 0) || (angleError < 0 && oldAngleError > 0)) {
		angleErrorSum = 0.0f;
	}

	// --- 3. Final PID Equation ---
	float angleCorrection = (KPW * angleError) + (KIW * angleErrorSum) + (KDW * dAngleError);
    float distanceCorrection = KPD * distanceError + KDD * (distanceError - oldDistanceError);

    // ---------------------------------------------------------
    // --- ACCELERATION PROFILING (SLEW RATE LIMITING) ---
    // ---------------------------------------------------------

	// Ramp up Distance Speed Limit
	if (currentDistSpeedLimit < MAX_SPD) {
		currentDistSpeedLimit += ACCEL_DIST;
	}

	// Ramp up Angle Speed Limit
	if (currentAngleSpeedLimit < MAX_TURN_SPD) {
		currentAngleSpeedLimit += ACCEL_ANGLE;
	}

	// Clamp distanceCorrection to the ramping limit
	if (distanceCorrection >  currentDistSpeedLimit) distanceCorrection =  currentDistSpeedLimit;
	if (distanceCorrection < -currentDistSpeedLimit) distanceCorrection = -currentDistSpeedLimit;

	// Clamp angleCorrection to the ramping limit
	if (angleCorrection >  currentAngleSpeedLimit) angleCorrection =  currentAngleSpeedLimit;
	if (angleCorrection < -currentAngleSpeedLimit) angleCorrection = -currentAngleSpeedLimit;

	// ---------------------------------------------------------

    // --- Motor Mixing ---
    float leftPWM  = distanceCorrection + angleCorrection;
    float rightPWM = distanceCorrection - angleCorrection;


    setMotorLPWM(leftPWM);
    setMotorRPWM(rightPWM);

    // --- Done Detection ---
    if (distanceError > -DIST_THRESH && distanceError < DIST_THRESH &&
        angleError    > -ANG_THRESH  && angleError    < ANG_THRESH)
    {
        stableCount++;
        if (stableCount >= DONE_CYCLES)
            isDone = 1;
    }
    else
    {
        stableCount = 0;
        isDone      = 0;
    }
}

void startPID(void)
{
    pidRunning = 1;
}

void stopPID(void)
{
    pidRunning = 0;
}

int8_t PIDdone(void)
{
    return isDone;
}

void turnRelative(int16_t delta_angle)
{
    // Add the turn to your current target angle
    goalAngle += (float)delta_angle;

    // Keep the goal angle bounded between -180 and +180
    // so it matches the raw output range of the gyroscope
    while (goalAngle > 180.0f)  goalAngle -= 360.0f;
    while (goalAngle < -180.0f) goalAngle += 360.0f;

    angleErrorSum = 0.0f;
}

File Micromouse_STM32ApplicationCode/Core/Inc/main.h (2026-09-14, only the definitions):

#define RightButton_Pin GPIO_PIN_15
#define RightButton_GPIO_Port GPIOC
#define RightEncoderCh1_Pin GPIO_PIN_0
#define RightEncoderCh1_GPIO_Port GPIOA
#define RightEncoderCh2_Pin GPIO_PIN_1
#define RightEncoderCh2_GPIO_Port GPIOA
#define RightEmitter_Pin GPIO_PIN_2
#define RightEmitter_GPIO_Port GPIOA
#define RightReceiver_Pin GPIO_PIN_3
#define RightReceiver_GPIO_Port GPIOA
#define Right45Receiver_Pin GPIO_PIN_4
#define Right45Receiver_GPIO_Port GPIOA
#define Right45Emitter_Pin GPIO_PIN_5
#define Right45Emitter_GPIO_Port GPIOA
#define FrontRightReceiver_Pin GPIO_PIN_6
#define FrontRightReceiver_GPIO_Port GPIOA
#define FrontRightEmitter_Pin GPIO_PIN_7
#define FrontRightEmitter_GPIO_Port GPIOA
#define FrontLeftReceiver_Pin GPIO_PIN_4
#define FrontLeftReceiver_GPIO_Port GPIOC
#define FrontLeftEmitter_Pin GPIO_PIN_5
#define FrontLeftEmitter_GPIO_Port GPIOC
#define Left45Receiver_Pin GPIO_PIN_0
#define Left45Receiver_GPIO_Port GPIOB
#define LeftReceiver_Pin GPIO_PIN_1
#define LeftReceiver_GPIO_Port GPIOB
#define I2C_SCL_Gyro_Pin GPIO_PIN_10
#define I2C_SCL_Gyro_GPIO_Port GPIOB
#define I2C_SDA_Gyro_Pin GPIO_PIN_11
#define I2C_SDA_Gyro_GPIO_Port GPIOB
#define Left45Emitter_Pin GPIO_PIN_12
#define Left45Emitter_GPIO_Port GPIOB
#define LeftEmitter_Pin GPIO_PIN_13
#define LeftEmitter_GPIO_Port GPIOB
#define LeftEncoderCh1_Pin GPIO_PIN_8
#define LeftEncoderCh1_GPIO_Port GPIOA
#define LeftEncoderCh2_Pin GPIO_PIN_9
#define LeftEncoderCh2_GPIO_Port GPIOA
#define LeftButton_Pin GPIO_PIN_12
#define LeftButton_GPIO_Port GPIOA
#define BlueLED_Pin GPIO_PIN_2
#define BlueLED_GPIO_Port GPIOD
#define GreenLED_Pin GPIO_PIN_3
#define GreenLED_GPIO_Port GPIOB
#define YellowLED_Pin GPIO_PIN_4
#define YellowLED_GPIO_Port GPIOB
#define RedLED_Pin GPIO_PIN_5
#define RedLED_GPIO_Port GPIOB
#define MotorCh1_Pin GPIO_PIN_6
#define MotorCh1_GPIO_Port GPIOB
#define MotorCh2_Pin GPIO_PIN_7
#define MotorCh2_GPIO_Port GPIOB
#define MotorCh3_Pin GPIO_PIN_8
#define MotorCh3_GPIO_Port GPIOB
#define MotorCh4_Pin GPIO_PIN_9
#define MotorCh4_GPIO_Port GPIOB
#define CORRECTIONCOUNT 10

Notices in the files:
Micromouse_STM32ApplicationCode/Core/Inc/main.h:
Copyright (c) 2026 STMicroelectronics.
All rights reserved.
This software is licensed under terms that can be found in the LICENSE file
